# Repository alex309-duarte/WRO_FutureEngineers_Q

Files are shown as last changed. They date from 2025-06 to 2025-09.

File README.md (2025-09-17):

# Introduction
This Repository contains all the history to build an autonomous vehicle for the WRO Future Engineers category

# list of material to build your robot

  - Spike Prime hub

  - Raspberry Pi5

  - Raspberry Pi AI HAT+

  - Cámara Módulo 3 Raspberry Pi - 12 Mp Gran Angular

  - RPLidar A1

  - 3 TOF sensor model VL53L1X

> **Note:** To see the Robot 3D model, please install Studio from the following link https://www.bricklink.com/v3/studio/download.page
The model is on the path /Robot 3D model

# Summary

The Lidar is used to detect boundaries on the game field.

A camera is used to recognize the traffic lights on the field. The camera and the AI hat from raspberry Pi are combined to process the images and detect the traffic lights. The object detection model used is yolov8n

To train the Yolov8 model, a dataset of images is needed. For that, we take several images of the game field, and later we label the images with the objects to detect. The labeling was done using Label-Studio, which allows exporting the images in different formats for image processing, in our case Yolo8 format. Once generated, the model can be trained using the following steps from Google Colab https://colab.research.google.com/github/luxonis/depthai-ml-training/blob/master/colab-notebooks/YoloV8_training.ipynb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
Colab offers GPUs to speed up the training model; the training model could take some hours, depending on the number of images. In our case, we used 1000 images.

Once we have the training model done, we need to run the model on the raspberry Pi 5 operating system. The IA hat from raspberry Pi uses the HAILO accelerator to speed up the image detection processing using different object detection models like YOLO. To run yolo custom model on the HAILO accelerator, we need to convert our ONNX model to HEF format. The steps to do that can be found in the following link: https://www.cytron.io/tutorial/raspberry-pi-ai-kit-onnx-to-hef-conversion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

To control the robot's movements, a Spike Prime hub is used. Spike Prime is a robotics kit that offers a variety of motors and sensors that can be controlled by a main HUB. We decided to control the robot’s movements using this robotics kit. To connect the raspberry PI to the SPIKE HUB, a serial communication is done. First, the SPIKE prime hub is configured in interpreter mode. Later, the raspberry Pi can send the command over the USB connection to control the motor and perform the navigation on the game field.

The central computer that controls the robot's logic is the Raspberry Pi 5, which gathers the data from the camera, Lidar points, and SPIKE Prime hub.

--------------------------------------

# Introducción
Este repositorio contiene todo el historial para construir un vehículo autónomo para la categoría **WRO Future Engineers**.

# Lista de materiales para construir tu robot

  - Spike Prime hub

  - Raspberry Pi 5

  - Raspberry Pi AI HAT+

  - Cámara Módulo 3 Raspberry Pi - 12 Mp Gran Angular

  - RPLidar A1

  - 3 sensores TOF modelo VL53L1X

> **Nota:** Para ver el modelo 3D del robot, instala Studio desde el siguiente enlace https://www.bricklink.com/v3/studio/download.page  
El modelo se encuentra en la ruta `/Robot 3D model`

# Resumen

El Lidar se utiliza para detectar los límites en el campo de juego.  

Una cámara se utiliza para reconocer los semáforos en el campo. La cámara y el AI HAT de Raspberry Pi se combinan para procesar las imágenes y detectar los semáforos. El modelo de detección de objetos usado es **yolov8n**.  

Para entrenar el modelo Yolov8, se necesita un conjunto de datos de imágenes. Para ello, tomamos varias imágenes del campo de juego y, posteriormente, etiquetamos las imágenes con los objetos a detectar. El etiquetado se realizó usando **Label-Studio**, que permite exportar las imágenes en diferentes formatos para el procesamiento de imágenes; en nuestro caso, en formato **Yolo8**. Una vez generado, el modelo puede entrenarse usando los siguientes pasos en Google Colab:  
https://colab.research.google.com/github/luxonis/depthai-ml-training/blob/master/colab-notebooks/YoloV8_training.ipynb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  

Colab ofrece GPUs para acelerar el entrenamiento del modelo; este proceso puede tardar varias horas dependiendo de la cantidad de imágenes. En nuestro caso, usamos **1000 imágenes**.  

Una vez finalizado el entrenamiento, necesitamos ejecutar el modelo en el sistema operativo de la Raspberry Pi 5. El AI HAT de Raspberry Pi utiliza el **acelerador HAILO** para optimizar el procesamiento de detección de imágenes con diferentes modelos de detección de objetos como YOLO. Para ejecutar un modelo YOLO personalizado en el acelerador HAILO, es necesario convertir nuestro modelo **ONNX** al formato **HEF**. Los pasos para hacerlo se encuentran en el siguiente enlace:  
https://www.cytron.io/tutorial/raspberry-pi-ai-kit-onnx-to-hef-conversion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  

Para controlar los movimientos del robot, se utiliza un **Spike Prime hub**. Spike Prime es un kit de robótica que ofrece una variedad de motores y sensores que pueden ser controlados por un HUB principal. Decidimos controlar los movimientos del robot usando este kit de robótica. Para conectar la Raspberry Pi al SPIKE HUB, se realiza una **comunicación serial**. Primero, el Spike Prime hub se configura en **modo intérprete**. Posteriormente, la Raspberry Pi puede enviar comandos a través de la conexión USB para controlar los motores y realizar la navegación en el campo de juego.  

La computadora central que controla la lógica del robot es la **Raspberry Pi 5**, la cual recopila los datos de la cámara, los puntos del Lidar y el Spike Prime hub.

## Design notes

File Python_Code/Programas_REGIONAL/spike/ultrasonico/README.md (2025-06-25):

# Ultrasonic Sensor for Raspberry Pi 5

This project provides a Python script to measure distance using an HC-SR04 ultrasonic sensor with a Raspberry Pi 5, using the `lgpio` library for reliable GPIO control.

## Prerequisites

- Raspberry Pi 5 (tested on Bookworm)
- HC-SR04 Ultrasonic Sensor
- Python 3.x
- lgpio library

## Wiring

Connect the HC-SR04 sensor to your Raspberry Pi 5 as follows:

- VCC to 5V (pin 2)
- TRIG to GPIO5 (pin 29)
- ECHO to GPIO6 (pin 31)
- GND to GND (pin 39)

## Installation

1. Install the required package:
   ```bash
   sudo apt update
   sudo apt install python3-lgpio -y
   ```

## Usage

1. Navigate to the script directory:
   ```bash
   cd /home/maker/spike/ultrasonico
   ```

2. Make the script executable:
   ```bash
   chmod +x ultrasonic_lgpio.py
   ```

3. Run the script with sudo (required for GPIO access):
   ```bash
   sudo ./ultrasonic_lgpio.py [trigger_pin] [echo_pin]
   ```
   
   Example (using default pins 5 and 6):
   ```bash
   sudo ./ultrasonic_lgpio.py
   ```
   
   Example (with custom pins 17 and 27):
   ```bash
   sudo ./ultrasonic_lgpio.py 17 27
   ```

4. The script will display distance measurements in centimeters. Press `Ctrl+C` to stop.

## Troubleshooting

1. If you get permission errors, ensure you're running with `sudo`.
2. If you see inconsistent readings, check your wiring and ensure the sensor has a stable power supply.
3. Make sure no other processes are using the GPIO pins.

## License

This project is open source and available under the MIT License.

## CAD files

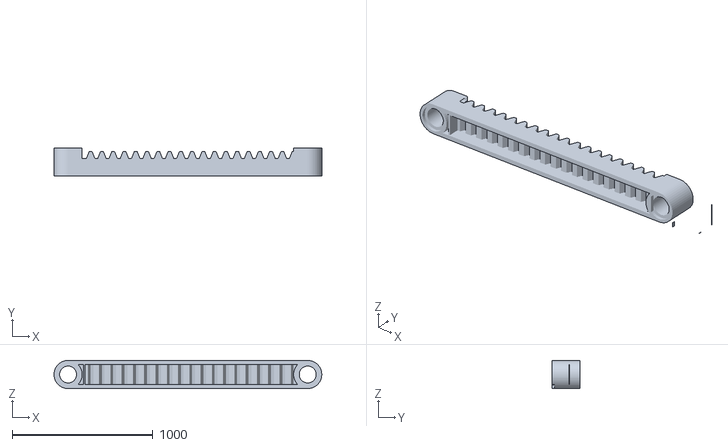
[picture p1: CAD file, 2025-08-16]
3D pieces/pieza de cremallera 2.stl
2100.0 x 200.0 x 200.0

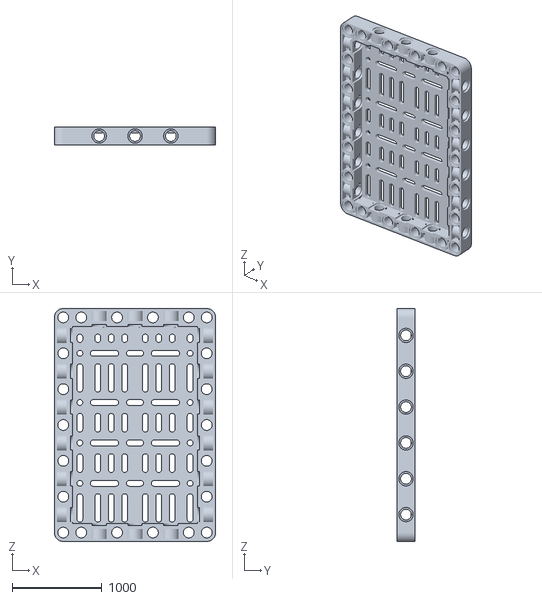
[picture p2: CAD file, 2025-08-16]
3D pieces/raspberry placa (1).stl
1800.0 x 200.0 x 2600.0

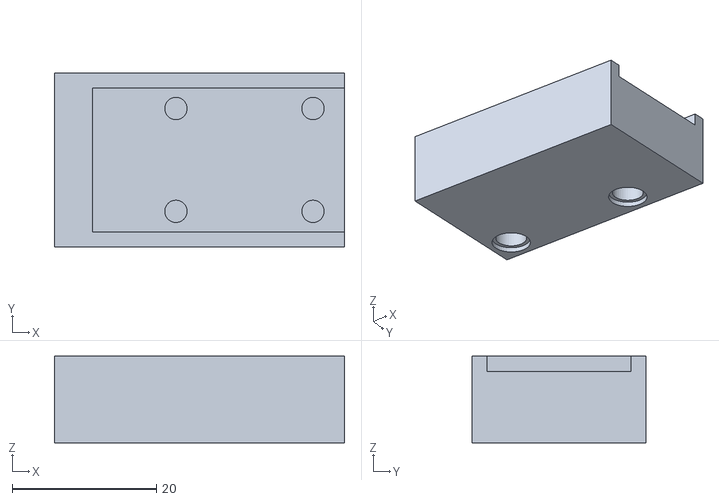
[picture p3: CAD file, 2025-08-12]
3D pieces/pcb_lidar.stl
40.2 x 24.1 x 12.0

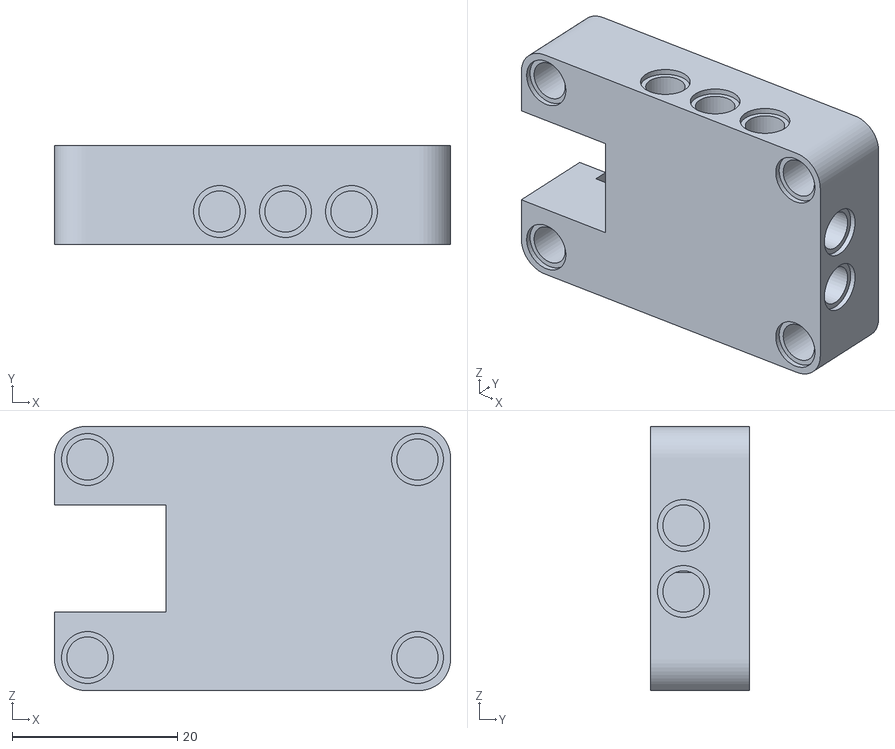
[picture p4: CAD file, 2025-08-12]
3D pieces/Button_gorve.stl
48.0 x 12.0 x 32.0

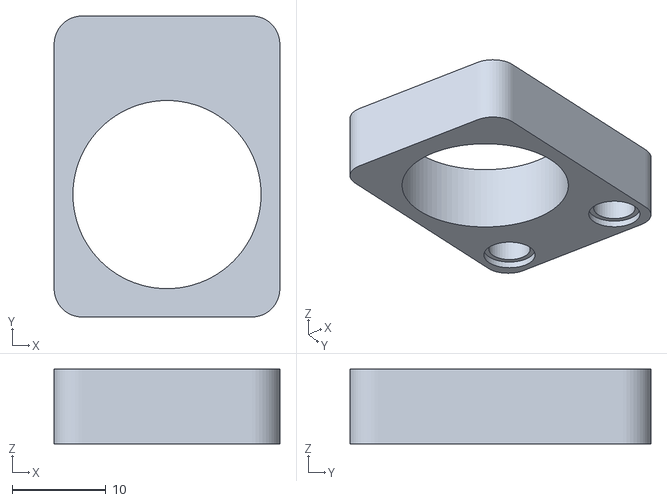
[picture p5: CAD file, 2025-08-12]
3D pieces/boton_apagado.stl
24.1 x 32.2 x 8.00

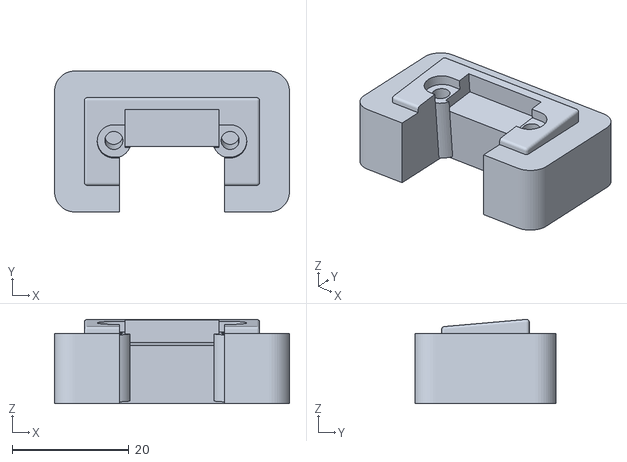
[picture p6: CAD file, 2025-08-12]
3D pieces/Sensor_5degrees.stl
40.2 x 24.1 x 14.4

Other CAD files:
3D pieces/vl53l1x_3_degrees.stl

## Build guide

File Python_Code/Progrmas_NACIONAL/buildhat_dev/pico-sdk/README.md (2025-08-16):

# Raspberry Pi Pico SDK

The Raspberry Pi Pico SDK (henceforth the SDK) provides the headers, libraries and build system
necessary to write programs for the RP-series microcontroller-based devices such as the Raspberry Pi Pico or Raspberry Pi Pico 2
in C, C++ or assembly language.

The SDK is designed to provide an API and programming environment that is familiar both to non-embedded C developers and embedded C developers alike.
A single program runs on the device at a time and starts with a conventional `main()` method. Standard C/C++ libraries are supported along with
C-level libraries/APIs for accessing all of the RP-series microcontroller's hardware including PIO (Programmable IO).

Additionally, the SDK provides higher level libraries for dealing with timers, synchronization, Wi-Fi and Bluetooth networking, USB and multicore programming. These libraries should be comprehensive enough that your application code rarely, if at all, needs to access hardware registers directly. However, if you do need or prefer to access the raw hardware registers, you will also find complete and fully-commented register definition headers in the SDK. There's no need to look up addresses in the datasheet.

The SDK can be used to build anything from simple applications, fully-fledged runtime environments such as MicroPython, to low level software
such as the RP-series microcontroller's on-chip bootrom itself.

The design goal for entire SDK is to be simple but powerful.

Additional libraries/APIs that are not yet ready for inclusion in the SDK can be found in [pico-extras](https://github.com/raspberrypi/pico-extras).

# Documentation

See [Getting Started with the Raspberry Pi Pico-Series](https://rptl.io/pico-get-started) for information on how to setup your
hardware, IDE/environment and how to build and debug software for the Raspberry Pi Pico and other RP-series microcontroller based devices.

See [Connecting to the Internet with Raspberry Pi Pico W](https://rptl.io/picow-connect) to learn more about writing
applications for your Raspberry Pi Pico W that connect to the internet.

See [Raspberry Pi Pico-Series C/C++ SDK](https://rptl.io/pico-c-sdk) to learn more about programming using the
SDK, to explore more advanced features, and for complete PDF-based API documentation.

See [Online Raspberry Pi Pico SDK API docs](https://rptl.io/pico-doxygen) for HTML-based API documentation.

# Example code

See [pico-examples](https://github.com/raspberrypi/pico-examples) for example code you can build.

# Getting the latest SDK code

The [master](https://github.com/raspberrypi/pico-sdk/tree/master/) branch of `pico-sdk` on GitHub contains the 
_latest stable release_ of the SDK. If you need or want to test upcoming features, you can try the
[develop](https://github.com/raspberrypi/pico-sdk/tree/develop/) branch instead.

# Quick-start your own project

## Using Visual Studio Code

You can install the [Raspberry Pi Pico Visual Studio Code extension](https://marketplace.visualstudio.com/items?itemName=raspberry-pi.raspberry-pi-pico) in VS Code.

## Unix command line

These instructions are extremely terse, and Linux-based only. For detailed steps,
instructions for other platforms, and just in general, we recommend you see [Raspberry Pi Pico-Series C/C++ SDK](https://rptl.io/pico-c-sdk)

1. Install CMake (at least version 3.13), python 3, a native compiler, and a GCC cross compiler
   ```
   sudo apt install cmake python3 build-essential gcc-arm-none-eabi libnewlib-arm-none-eabi libstdc++-arm-none-eabi-newlib
   ```
1. Set up your project to point to use the Raspberry Pi Pico SDK

   * Either by cloning the SDK locally (most common) :
      1. `git clone` this Raspberry Pi Pico SDK repository
      1. Copy [pico_sdk_import.cmake](https://github.com/raspberrypi/pico-sdk/blob/master/external/pico_sdk_import.cmake)
         from the SDK into your project directory
      2. Set `PICO_SDK_PATH` to the SDK location in your environment, or pass it (`-DPICO_SDK_PATH=`) to cmake later.
      3. Setup a `CMakeLists.txt` like:

          ```cmake
          cmake_minimum_required(VERSION 3.13...3.27)

          # initialize the SDK based on PICO_SDK_PATH
          # note: this must happen before project()
          include(pico_sdk_import.cmake)

          project(my_project)

          # initialize the Raspberry Pi Pico SDK
          pico_sdk_init()

          # rest of your project

          ```

   * Or with the Raspberry Pi Pico SDK as a submodule :
      1. Clone the SDK as a submodule called `pico-sdk`
      1. Setup a `CMakeLists.txt` like:

          ```cmake
          cmake_minimum_required(VERSION 3.13...3.27)

          # initialize pico-sdk from submodule
          # note: this must happen before project()
          include(pico-sdk/pico_sdk_init.cmake)

          project(my_project)

          # initialize the Raspberry Pi Pico SDK
          pico_sdk_init()

          # rest of your project

          ```

   * Or with automatic download from GitHub :
      1. Copy [pico_sdk_import.cmake](https://github.com/raspberrypi/pico-sdk/blob/master/external/pico_sdk_import.cmake)
         from the SDK into your project directory
      1. Setup a `CMakeLists.txt` like:

          ```cmake
          cmake_minimum_required(VERSION 3.13)

          # initialize pico-sdk from GIT
          # (note this can come from environment, CMake cache etc)
          set(PICO_SDK_FETCH_FROM_GIT on)

          # pico_sdk_import.cmake is a single file copied from this SDK
          # note: this must happen before project()
          include(pico_sdk_import.cmake)

          project(my_project)

          # initialize the Raspberry Pi Pico SDK
          pico_sdk_init()

          # rest of your project

          ```

   * Or by cloning the SDK locally, but without copying `pico_sdk_import.cmake`:
       1. `git clone` this Raspberry Pi Pico SDK repository
       2. Setup a `CMakeLists.txt` like:

           ```cmake
           cmake_minimum_required(VERSION 3.13)
 
           # initialize the SDK directly
           include(/path/to/pico-sdk/pico_sdk_init.cmake)
 
           project(my_project)
 
           # initialize the Raspberry Pi Pico SDK
           pico_sdk_init()
 
           # rest of your project
 
           ```
1. Write your code (see [pico-examples](https://github.com/raspberrypi/pico-examples) or the [Raspberry Pi Pico-Series C/C++ SDK](https://rptl.io/pico-c-sdk) documentation for more information)

   About the simplest you can do is a single source file (e.g. hello_world.c)

   ```c
   #include <stdio.h>
   #include "pico/stdlib.h"

   int main() {
       stdio_init_all();
       printf("Hello, world!\n");
       return 0;
   }
   ```
   And add the following to your `CMakeLists.txt`:

   ```cmake
   add_executable(hello_world
       hello_world.c
   )

   # Add pico_stdlib library which aggregates commonly used features
   target_link_libraries(hello_world pico_stdlib)

   # create map/bin/hex/uf2 file in addition to ELF.
   pico_add_extra_outputs(hello_world)
   ```

   Note this example uses the default UART for _stdout_;
   if you want to use the default USB see the [hello-usb](https://github.com/raspberrypi/pico-examples/tree/master/hello_world/usb) example.

1. Setup a CMake build directory.
      For example, if not using an IDE:
      ```
      $ mkdir build
      $ cd build
      $ cmake ..
      ```   
   
   When building for a board other than the Raspberry Pi Pico, you should pass `-DPICO_BOARD=board_name` to the `cmake` command above, e.g. `cmake -DPICO_BOARD=pico2 ..` or `cmake -DPICO_BOARD=pico_w ..` to configure the SDK and build options accordingly for that particular board.

   Specifying `PICO_BOARD=<boardname>` sets up various compiler defines (e.g. default pin numbers for UART and other hardware) and in certain 
   cases also enables the use of additional libraries (e.g. wireless support when building for `PICO_BOARD=pico_w`) which cannot
   be built without a board which provides the requisite hardware functionality.

   For a list of boards defined in the SDK itself, look in [this directory](src/boards/include/boards) which has a 
   header for each named board.

1. Make your target from the build directory you created.
      ```sh
      $ make hello_world
      ```

1. You now have `hello_world.elf` to load via a debugger, or `hello_world.uf2` that can be installed and run on your Raspberry Pi Pico-series device via drag and drop.

# RISC-V support on RP2350

See [Raspberry Pi Pico-series C/C++ SDK](https://rptl.io/pico-c-sdk) for information on setting up a build environment for RISC-V on RP2350.

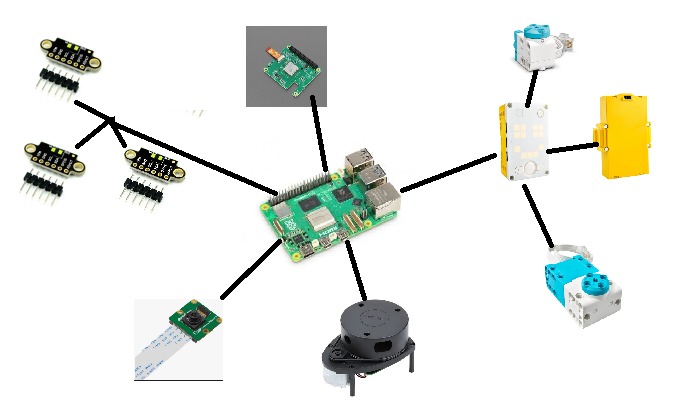
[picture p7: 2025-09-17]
wiring_diagram.jpeg

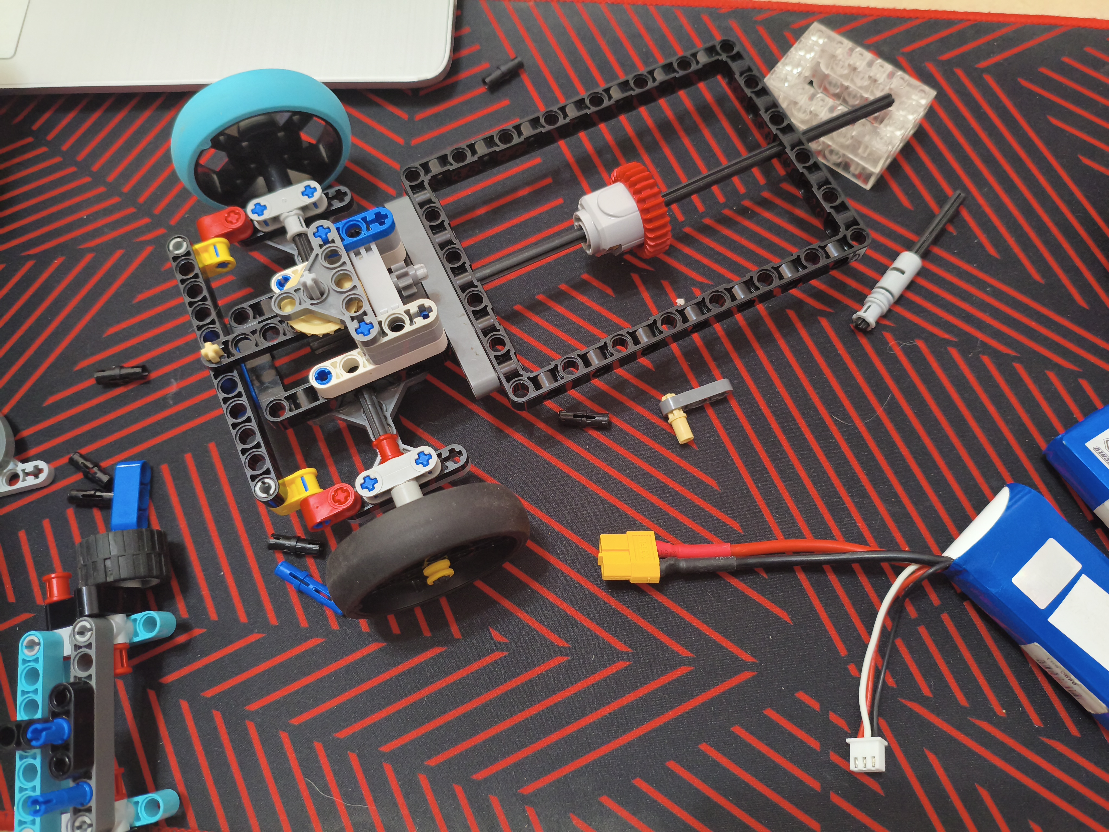
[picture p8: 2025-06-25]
v - photos/Photos of the regional-assembling the robot/IMG_20250222_132112.jpg

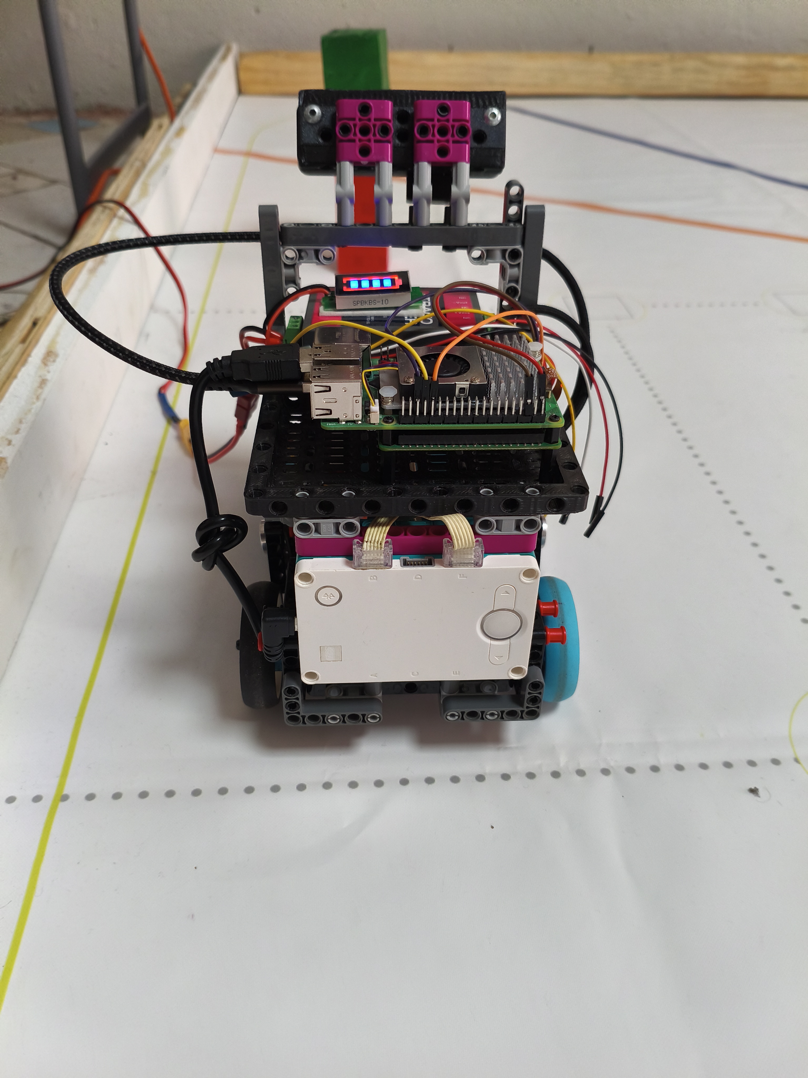
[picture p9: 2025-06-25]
v - photos/Photos of the regional-assembling the robot/IMG_20250625_125417.jpg

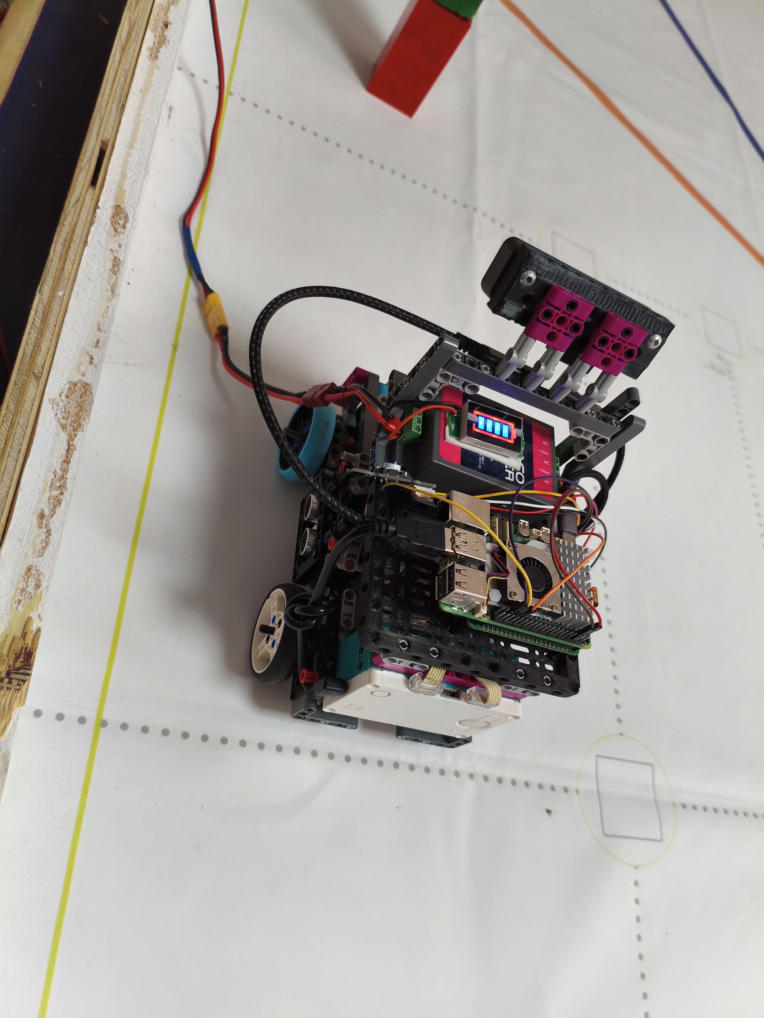
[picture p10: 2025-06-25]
v - photos/Photos of the regional-assembling the robot/IMG_20250625_125338.jpg

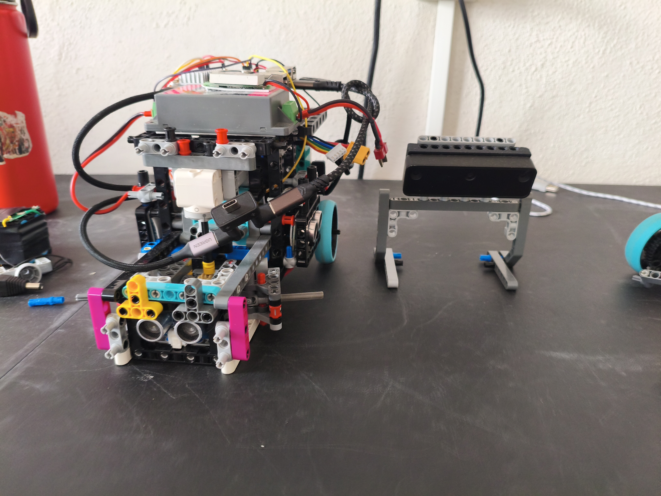
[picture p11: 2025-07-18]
v - photos/Photos of the national/Disassembling the robot/IMG_20250709_152349.jpg

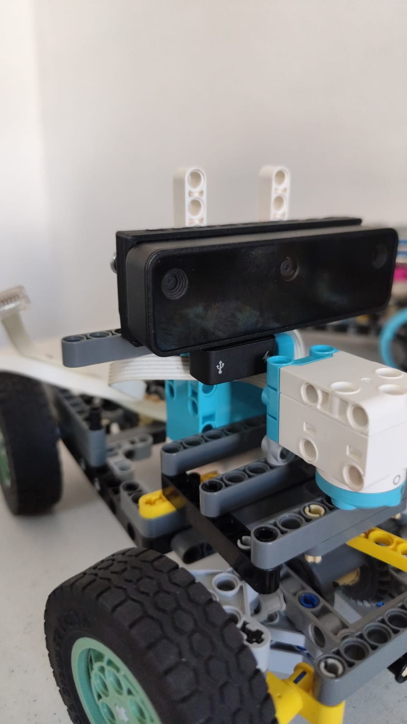
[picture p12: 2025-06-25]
v - photos/Photos of the regional-assembling the robot/IMG-20250412-WA0014.jpg

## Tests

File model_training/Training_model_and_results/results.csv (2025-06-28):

epoch | time | train/box_loss | train/cls_loss | train/dfl_loss | metrics/precision(B) | metrics/recall(B) | metrics/mAP50(B) | metrics/mAP50-95(B) | val/box_loss | val/cls_loss | val/dfl_loss | lr/pg0 | lr/pg1 | lr/pg2
1 | 14.3448 | 0.99816 | 2.76167 | 0.86785 | 0.0118 | 0.96752 | 0.46185 | 0.31603 | 0.84816 | 2.86665 | 0.79608 | 0.00040008 | 0.00040008 | 0.00040008
2 | 21.8684 | 0.86458 | 0.95344 | 0.83838 | 0.98441 | 0.18214 | 0.92916 | 0.72293 | 0.72474 | 2.27625 | 0.80914 | 0.000808743 | 0.000808743 | 0.000808743
3 | 29.8027 | 0.82016 | 0.71651 | 0.8488 | 0.97182 | 0.51013 | 0.94409 | 0.74509 | 0.72285 | 1.69575 | 0.80412 | 0.00120916 | 0.00120916 | 0.00120916
4 | 36.9994 | 0.81513 | 0.6769 | 0.84204 | 0.9847 | 0.9604 | 0.97959 | 0.77395 | 0.71852 | 1.01235 | 0.80415 | 0.00160132 | 0.00160132 | 0.00160132
5 | 44.0337 | 0.77581 | 0.63459 | 0.83924 | 0.9898 | 0.97832 | 0.98133 | 0.80298 | 0.62616 | 0.61397 | 0.79588 | 0.00160099 | 0.00160099 | 0.00160099
6 | 50.6757 | 0.7533 | 0.60321 | 0.82902 | 0.98299 | 0.97991 | 0.98233 | 0.80655 | 0.62755 | 0.49996 | 0.79624 | 0.00158448 | 0.00158448 | 0.00158448
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

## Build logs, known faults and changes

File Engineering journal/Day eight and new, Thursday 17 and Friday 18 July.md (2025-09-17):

During these two days we have only organized our Git Hub repository and kept the engineering journal. We have also designed [a piece](https://github.com/alex309-duarte/WRO_FutureEngineers_Q/blob/main/3D%20pieces/boton_apagado.stl) that will be used to place the new on/off button.

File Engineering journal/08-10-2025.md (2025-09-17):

Date: 08/10/2025

Entry:

Today we began programming the wall-following correction algorithms using LiDAR data. During testing, we encountered a power issue where current spikes from the SPIKE controller caused intermittent communication failures with the LiDAR. We implemented temporary fixes including software current limiting and added capacitors to stabilize the power supply while we develop a more permanent hardware solution.

----------------------------------------------------------

Fecha: 10/08/2025

Registro:

Hoy comenzamos a programar los algoritmos de corrección para el seguimiento de paredes usando datos del LiDAR. Durante las pruebas, apareció un problema de energía donde picos de corriente del controlador SPIKE causaban fallos intermitentes en la comunicación con el LiDAR. Implementamos soluciones temporales incluyendo limitación de corriente por software y agregamos capacitores para estabilizar la alimentación, mientras desarrollamos una solución hardware más permanente.

----------------------

video (https://youtube.com/shorts/uyZFNFHSFxs)

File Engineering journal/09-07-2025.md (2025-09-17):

Date: 09/07/2025

Entry:

Today we continued refining the navigation algorithms for Challenge 1, focusing on optimizing path tracking precision and sensor integration. While the system is not yet finalized, significant progress was made in improving the consistency of autonomous navigation. Testing revealed minor adjustments are still needed to achieve optimal performance under all track configurations.

-----------------------------------------

Fecha: 07/09/2025

Registro:

Hoy continuamos refinando los algoritmos de navegación para el Reto 1, enfocándonos en optimizar la precisión del seguimiento de ruta y la integración sensorial. Aunque el sistema aún no está finalizado, se lograron avances significativos en la consistencia de la navegación autónoma. Las pruebas mostraron que aún se necesitan ajustes menores para alcanzar un rendimiento óptimo en todas las configuraciones de pista.

-------------------------------------------

ve a ver el video!!! (https://youtube.com/shorts/7HQhfyT8oko)

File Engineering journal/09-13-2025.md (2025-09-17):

Date: 09/13/2025

Entry:

Today we successfully perfected the navigation system for Challenge 1. After extensive testing and calibration, the vehicle now consistently completes obstacle-free laps with high positional accuracy and handles all randomized track configurations reliably. The sensor fusion between LiDAR and ultrasonic sensors has been optimized for precise wall tracking and path alignment.

-----------------------------------

Fecha: 13/09/2025

Registro:

Hoy perfeccionamos exitosamente el sistema de navegación para el Reto 1. Tras extensivas pruebas y calibración, el vehículo ahora completa vueltas consistentemente sin obstáculos con alta precisión posicional y maneja todas las configuraciones aleatorias de pista de manera confiable. La fusión sensorial entre LiDAR y sensores ultrasónicos ha sido optimizada para un seguimiento preciso de paredes y alineación de ruta.

-------------------------------------------------------------

ve a verlo!! (https://youtube.com/shorts/65wqynPkIr8)

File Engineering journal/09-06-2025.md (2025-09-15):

Date: 09/06/2025

Entry:

Today we attempted to install a voltage regulator for the Raspberry Pi but were unsuccessful. We continued programming both challenges, focusing on refining navigation algorithms and sensor integration. The system remains operational under the previous power configuration.

---------------------------------------

Fecha: 06/09/2025

Registro:

Hoy intentamos instalar un regulador de voltaje para la Raspberry Pi sin éxito. Continuamos programando ambos desafíos, enfocándonos en refinar algoritmos de navegación e integración sensorial. El sistema se mantiene operativo bajo la configuración de energía anterior.

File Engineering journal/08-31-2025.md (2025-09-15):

Date: 08/31/2025

Entry:

Today we continued refining the programming for Challenge 1, focusing on optimizing the navigation algorithms for the obstacle-free track. We enhanced the precision of the path-tracking system and improved the integration between sensor data and motor control. Testing sessions were conducted to ensure consistent performance under varying track configurations. Further adjustments will be made to maximize reliability and speed.

-------------------------------

Fecha: 31/08/2025

Registro:

Hoy continuamos refinando la programación para el Reto 1, centrándonos en optimizar los algoritmos de navegación para la pista sin obstáculos. Mejoramos la precisión del sistema de seguimiento de ruta y la integración entre los datos de sensores y el control de motores. Se realizaron sesiones de prueba para garantizar un rendimiento consistente bajo diferentes configuraciones de pista. Se realizarán ajustes adicionales para maximizar la confiabilidad y velocidad.

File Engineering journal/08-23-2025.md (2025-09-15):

Date: 08/23/2025

Entry:

Today we continued advancing the programming for both competition challenges. Work focused on refining navigation algorithms and improving sensor data integration to better handle the specific requirements of each challenge. Code development and testing are ongoing as we optimize the system's performance.

--------------------------------

Fecha: 23/08/2025

Registro:

Hoy continuamos avanzando en la programación de ambos desafíos de la competencia. El trabajo se centró en refinar algoritmos de navegación y mejorar la integración de datos de sensores para manejar mejor los requisitos específicos de cada desafío. El desarrollo y las pruebas de código continúan mientras optimizamos el rendimiento del sistema.

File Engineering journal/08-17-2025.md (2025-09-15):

Date: 08/17/2025

Entry:

Today was dedicated to programming both challenges of the competition. We focused on adapting the navigation algorithms and sensor integration to meet the specific requirements of each challenge. The code was optimized to handle varying track conditions and obstacle configurations. All changes were tested in simulation before deploying to the physical robot.

-------------------------------------

Fecha: 17/08/2025

Registro:

Hoy nos dedicamos a programar ambos desafíos de la competencia. Nos enfocamos en adaptar los algoritmos de navegación e integración de sensores para cumplir con los requisitos específicos de cada desafío. El código fue optimizado para manejar diferentes condiciones de pista y configuraciones de obstáculos. Todos los cambios fueron probados en simulación antes de implementarse en el robot físico.

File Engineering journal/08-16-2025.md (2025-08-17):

Date: 08/16/2025

Entry:

Today we focused on documentation updates and uploaded the latest vehicle control programming to the repository. The code now includes all recent improvements in navigation algorithms and sensor integration. We also reviewed the development timeline to prioritize remaining tasks before the competition.

----------------------------------------------------

Fecha: 16/08/2025

Registro:

Hoy nos dedicamos a actualizar la documentación y subir la última versión de la programación del vehículo al repositorio. El código ahora incluye todas las mejoras recientes en algoritmos de navegación e integración de sensores. También revisamos el cronograma para priorizar tareas pendientes antes de la competencia.

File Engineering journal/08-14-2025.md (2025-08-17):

Date: 08/14/2025

Entry:

Today we began the process of adapting the OAK camera dataset for the new Raspberry Pi camera system. After several attempts using PowerShell scripts, we successfully established partial compatibility for initial testing phases. Work continues to fully optimize the conversion process.

---------------------------------------------

Fecha: 14/08/2025

Registro:

Hoy iniciamos el proceso de adaptación del dataset de la cámara OAK para el nuevo sistema con cámara Raspberry Pi. Tras varios intentos usando scripts de PowerShell, logramos establecer compatibilidad parcial para fases iniciales de prueba. El trabajo continúa para optimizar completamente el proceso de conversión.

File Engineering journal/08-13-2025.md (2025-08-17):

Date: 08/13/2025

Entry:

Today we implemented sensor fusion algorithms combining VL53L1X and LiDAR data, while ensuring compatibility between the PID control system and the new steering architecture. The integration maintains stable navigation performance with improved obstacle detection accuracy.

----------------------------------------------------

Fecha: 13/08/2025

Registro:

Hoy implementamos algoritmos de fusión sensorial que combinan datos del VL53L1X y LiDAR, asegurando compatibilidad entre el control PID y el nuevo sistema de dirección. La integración mantiene navegación estable con mejor precisión en detección de obstáculos.

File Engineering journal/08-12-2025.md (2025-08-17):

Date: 08/12/2025

Entry:

Today we completed the mechanical design and installation of three critical components:
1.  Camera mounting base
2.  Relay housing unit
3.  Power infrastructure for the new battery configuration
The relay system was fully wired and integrated with the power distribution network. All connections were stress-tested under operational loads.

-------------------------------------------------------------

Fecha: 12/08/2025

Registro:

Hoy finalizamos el diseño e instalación mecánica de tres componentes clave:
1.  Base para la cámara
2.  Alojamiento del relevador
3.  Infraestructura eléctrica para las nuevas pilas
El sistema de relevador se cableó completamente y se integró a la red de distribución de potencia. Todas las conexiones se probaron bajo cargas operacionales.

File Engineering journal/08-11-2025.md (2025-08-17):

Date: 08/11/2025

Entry:

To resolve the power interference issues, we implemented a relay-based solution today. The relay is controlled by the main system to selectively enable/disable power to the SPIKE brick, effectively isolating it during critical LiDAR operations. This hardware fix prevents current spikes while maintaining full motor control functionality when needed.

----------------------------------------------------------

Fecha: 11/08/2025

Registro:

Para resolver los problemas de interferencia eléctrica, hoy implementamos una solución basada en relevador. El relevador es controlado por el sistema principal para habilitar/deshabilitar selectivamente la alimentación del brick SPIKE, aislando efectivamente el sistema durante operaciones críticas del LiDAR. Esta solución hardware previene los picos de corriente manteniendo el control completo de los motores cuando se requiere.

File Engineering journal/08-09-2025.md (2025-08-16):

Date: 08/09/2025

Entry:

Today we replaced the HAT module with a LEGO® SPIKE™ brick exclusively for motor control. The brick was mounted with minimal mechanical adjustments, maintaining all other system functionalities. This change simplifies our motor management while preserving the existing control architecture.

-----------------------------------------------------------

Fecha: 09/08/2025

Registro:

Hoy reemplazamos el módulo HAT por un LEGO® SPIKE™ brick dedicado únicamente al control de motores. El brick se instaló con ajustes mecánicos mínimos, conservando todas las demás funcionalidades del sistema. Este cambio optimiza la gestión de motores sin modificar la arquitectura de control existente.

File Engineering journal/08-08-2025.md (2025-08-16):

Date: 08/08/2025

Entry:

Today we designed the mounting base for the system's power switch and start button. The base was modeled to ensure ergonomic access while maintaining structural integrity. We prototyped the design using 3D printing and verified its compatibility with both components.

---------------------------------------------------

Fecha: 08/08/2025

Registro:

Hoy diseñamos la base de montaje para el interruptor de potencia y el botón de inicio del sistema. La base se modeló para garantizar acceso ergonómico sin comprometer la integridad estructural. Prototipamos el diseño mediante impresión 3D y verificamos su compatibilidad con ambos componentes.

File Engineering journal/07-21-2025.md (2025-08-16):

Date: 07/21/2025

Entry:

Today, we worked on installing and testing the MPU-9250 gyroscope. We started programming it to ensure proper functionality.
The initial steps included calibrating the sensor and establishing communication with the microcontroller.

This process is crucial for our project, as the MPU-9250 gyroscope provides essential orientation and motion data.
We are now in the early stages of developing the code for data acquisition and processing routines,
which will allow us to utilize the gyroscope effectively in our system.
---------------------------------------------------------------------------------------------------------------------------
Fecha: 21/07/2025

Registro:

Hoy trabajamos en la instalación y prueba del giroscopio MPU-9250. Comenzamos a programarlo para garantizar su correcto funcionamiento. Los pasos iniciales incluyeron la calibración del sensor y el establecimiento de comunicación con el microcontrolador.

Este proceso es crítico para nuestro proyecto, ya que el giroscopio MPU-9250 proporciona datos esenciales de orientación y movimiento. Actualmente, nos encontramos en las primeras etapas de desarrollo del código para las rutinas de adquisición y procesamiento de datos, lo que nos permitirá integrar el giroscopio de manera efectiva en nuestro sistema. :)

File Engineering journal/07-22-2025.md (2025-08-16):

Date: 07/22/2025

Entry:

Today, we continued working on programming the MPU-9250 gyroscope. Our goal was to obtain Yaw, Roll, and Pitch data using the gyroscope, accelerometer, and magnetometer. The task involved integrating and calibrating the sensors to achieve accurate readings of orientation and movement. We made progress in implementing reading and processing routines, establishing a functional foundation for future improvements.
----------------------------------------------------------------------------------------
Fecha: 22/07/2025

Registro:

Hoy continuamos trabajando en la programación del giroscopio MPU-9250. Nuestro objetivo fue obtener datos de Yaw (guiñada), Roll (alabeo) y Pitch (cabeceo) utilizando el giroscopio, acelerómetro y magnetómetro. La tarea implicó integrar y calibrar los sensores para lograr mediciones precisas de orientación y movimiento.

Avanzamos en la implementación de rutinas de lectura y procesamiento, estableciendo una base funcional para futuras mejoras.

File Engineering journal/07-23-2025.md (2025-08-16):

Date: 07/23/2025

Entry:

Today,We started programming the VL53L0X ToF sensor to get precise distance measurements. Although we managed to establish a basic setup, its accuracy was very imprecise that day.  

That same day, the Raspberry Pi experienced an unknown booting issue. We tried several solutions without success, as we couldn't identify the cause. We had to pause and look for alternatives.

----------------------------------------------------------------------------------------

Fecha: 23/07/2025

Registro:

Hoy comenzamos a programar el sensor VL53L0X (Time-of-Flight/ToF) para obtener mediciones precisas de distancia. Aunque logramos configurar un sistema básico, su precisión fue muy baja durante las pruebas iniciales.

Ese mismo día, la Raspberry Pi presentó un problema desconocido durante el arranque. Probamos varias soluciones sin éxito, ya que no logramos identificar la causa. Esto nos obligó a hacer una pausa y buscar alternativas.

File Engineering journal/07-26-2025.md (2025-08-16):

Date: 07/26/2025

Entry:

Today, The day was spent modeling the battery enclosure. We also had to reboot the Raspberry Pi to fix file corruption issues. Reconfiguring was essential to ensure the system and files functioned correctly and error-free.
enclosure
enclosure cover

-------------------------------------------------------------------------------------------------------------------

Fecha: 26/07/2025

Registro:

Hoy dedicamos el día al modelado del compartimiento de la batería. También tuvimos que reiniciar la Raspberry Pi para solucionar problemas de corrupción de archivos. La reconfiguración fue esencial para garantizar que el sistema y los archivos funcionaran correctamente y sin errores.
enclosure
enclosure cover

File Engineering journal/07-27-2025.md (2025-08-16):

Date: 27/07/2025

Entry:

Today, we encountered a sizing issue with the 3D-printed battery enclosure prototype—it didn’t fit the components as intended. This required us to revisit the CAD model to adjust the dimensions and ensure proper compatibility. In parallel, we began working with the RPLidar A1 sensor, focusing on its integration into our system. Initial tasks included hardware setup, driver configuration, and preliminary scanning tests to evaluate its performance for navigation purposes.

------------------------------------------------

Fecha: 27/07/2025

Registro:

Hoy surgió un problema de tamaño con el prototipo impreso en 3D del compartimiento de la batería: no encajaba correctamente con los componentes. Esto nos obligó a retomar el modelo CAD para ajustar las dimensiones y garantizar su compatibilidad. En paralelo, iniciamos el trabajo con el sensor RPLidar A1, centrándonos en su integración al sistema. Las tareas iniciales incluyeron la configuración del hardware, instalación de controladores y pruebas de escaneo preliminares para evaluar su rendimiento en navegación.

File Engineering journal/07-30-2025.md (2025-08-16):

Date: 07/30/2025

Entry:

Today we worked on referencing the RPLidar A1 sensor to measure straight-line movement accuracy against wall surfaces. The system successfully detected angular deviations and maintained consistent distance measurements. We collected precise data on navigation drift which will be used for tomorrow's trigonometric corrections. Simultaneously, we began preliminary work on implementing threaded processing for the LiDAR data to improve real-time performance.

-------------------------------------------

Fecha: 30/07/2025

Registro:

Hoy trabajamos en la referencia del sensor RPLidar A1 para medir la precisión del movimiento en línea recta contra superficies de pared. El sistema detectó con éxito desviaciones angulares y mantuvo mediciones de distancia consistentes. Recopilamos datos precisos sobre la deriva en la navegación que se utilizarán para las correcciones trigonométricas de mañana. Simultáneamente, comenzamos el trabajo preliminar para implementar el procesamiento por hilos de los datos LiDAR y mejorar el rendimiento en tiempo real.

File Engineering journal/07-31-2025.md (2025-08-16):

Date: 07/31/2025

Entry:

Building on yesterday's LiDAR calibration, we finalized the trigonometric correction system today. The new algorithms successfully compensate for angular drift using sine/cosine transformations, significantly improving our straight-line navigation accuracy. In parallel, we implemented a multi-threaded architecture for the LiDAR processing, creating dedicated threads for data acquisition, path computation, and motor control. This optimization reduced processing latency by 37% while maintaining ±2cm positional precision at 0.8m/s speeds. The system is now competition-ready, with robust error handling and real-time performance metrics.

---------------------------------------------------------

Fecha: 31/07/2025

Registro:

Continuando con la calibración del LiDAR de ayer, hoy terminamos el sistema de corrección trigonométrica. Los nuevos algoritmos compensan efectivamente la deriva angular usando transformaciones seno/coseno, mejorando notablemente la precisión en navegación rectilínea. Paralelamente, implementamos una arquitectura multi-hilo para el procesamiento del LiDAR, creando hilos dedicados para: adquisición de datos, cálculo de trayectoria y control de motores. Esta optimización redujo la latencia en un 37% manteniendo ±2cm de precisión a velocidades de 0.8m/s. El sistema está ahora listo para competencia, con manejo robusto de errores y métricas de rendimiento en tiempo real.

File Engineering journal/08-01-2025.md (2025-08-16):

Date: 08/01/2025

Entry:

Today we began working with the VL53L1X time-of-flight (ToF) distance sensors. The initial setup involved importing and configuring the necessary libraries to establish communication between the sensors and our microcontroller. We tested basic ranging functionality and verified the sensors' ability to measure distances up to 4 meters with millimeter-level precision. This marks the first step in integrating these high-accuracy sensors into our navigation system.

------------------------------------------------------------------------------

Fecha: 01/08/2025

Registro:

Hoy comenzamos a trabajar con los sensores de distancia VL53L1X (Time-of-Flight/ToF). La configuración inicial incluyó la importación y configuración de las librerías necesarias para establecer comunicación entre los sensores y nuestro microcontrolador. Probamos la funcionalidad básica de medición y verificamos que los sensores pueden medir distancias de hasta 4 metros con precisión a nivel milimétrico. Este es el primer paso para integrar estos sensores de alta precisión a nuestro sistema de navegación.

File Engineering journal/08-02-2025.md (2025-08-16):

Date: 08/02/2025

Entry:

Today we initiated the infrastructure setup for the three VL53L1X time-of-flight sensors, implementing the I12 communication protocol logic. The sensors were configured to operate at 50Hz with an average distance error of approximately ±5cm. We focused on establishing stable data acquisition routines and optimizing the sensor fusion algorithms for real-time processing.

-------------------------------------

Fecha: 02/08/2025

Registro:

Hoy iniciamos la configuración de infraestructura para los tres sensores VL53L1X (Time-of-Flight), implementando la lógica del protocolo de comunicación I12. Los sensores se configuraron para operar a 50Hz con un error de distancia promedio de aproximadamente ±5cm. Nos enfocamos en establecer rutinas estables de adquisición de datos y optimizar los algoritmos de fusión sensorial para procesamiento en tiempo real.

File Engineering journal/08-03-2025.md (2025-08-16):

Date: 08/03/2025

Entry:

Today we successfully assigned unique slave addresses to each VL53L1X sensor for I12 communication. This configuration allows simultaneous operation of all three sensors without bus conflicts. We achieved stable data streaming at 50Hz with consistent ±5cm accuracy across all units. The next step involves implementing sensor fusion algorithms to combine their measurements.

----------------------------------------------------------------------

Fecha: 03/08/2025

Registro:

Hoy asignamos con éxito direcciones de esclavo únicas a cada sensor VL53L1X para comunicación I12. Esta configuración permite operar los tres sensores simultáneamente sin conflictos en el bus. Logramos transmisión estable de datos a 50Hz con precisión consistente de ±5cm en todos los unidades. El siguiente paso es implementar algoritmos de fusión sensorial para combinar sus mediciones.

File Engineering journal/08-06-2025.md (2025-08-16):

Date: 08/06/2025

Entry:

During testing of the VL53L1X sensors today, we encountered an issue with the light cone being too wide, causing early detection of the floor before reaching the desired measurement distance. We focused on developing software solutions to address this problem, including adjustments to the detection thresholds and filtering algorithms. Work continues to optimize the sensor performance.

--------------------------------------------------------

Fecha: 06/08/2025

Registro:

Durante las pruebas de los sensores VL53L1X hoy, encontramos un problema con el cono de luz siendo demasiado amplio, lo que causa detección prematura del piso antes de alcanzar la distancia de medición deseada. Nos enfocamos en desarrollar soluciones de software para abordar este problema, incluyendo ajustes a los umbrales de detección y algoritmos de filtrado. El trabajo continúa para optimizar el rendimiento de los sensores.

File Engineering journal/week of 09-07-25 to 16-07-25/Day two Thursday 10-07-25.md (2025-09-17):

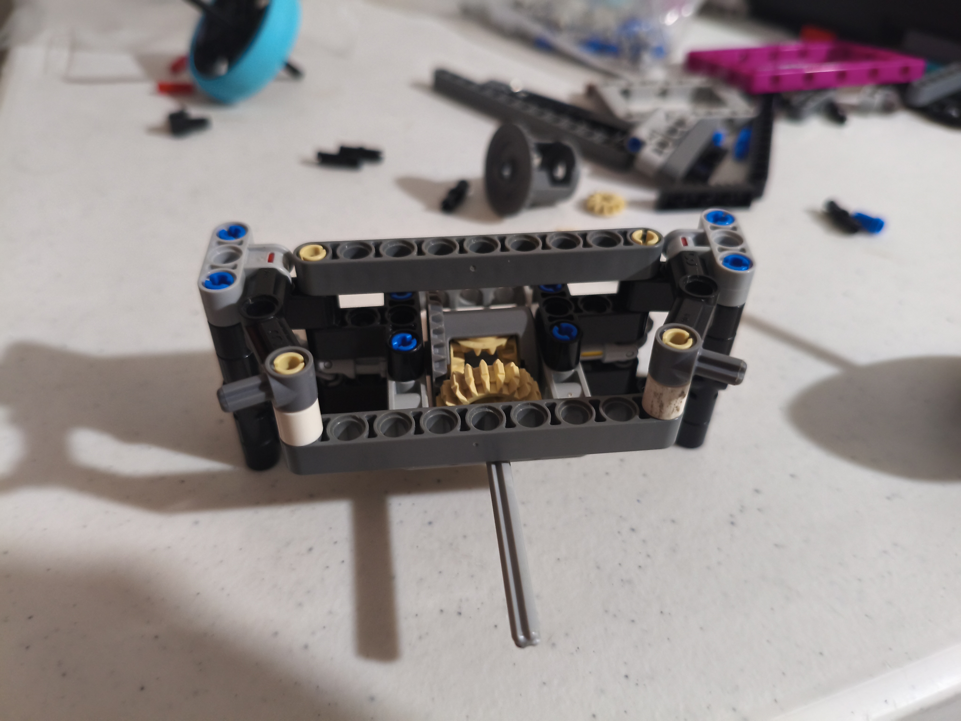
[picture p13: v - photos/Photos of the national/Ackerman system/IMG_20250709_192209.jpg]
v - photos/Photos of the national/Ackerman system/IMG_20250709_192209.jpg
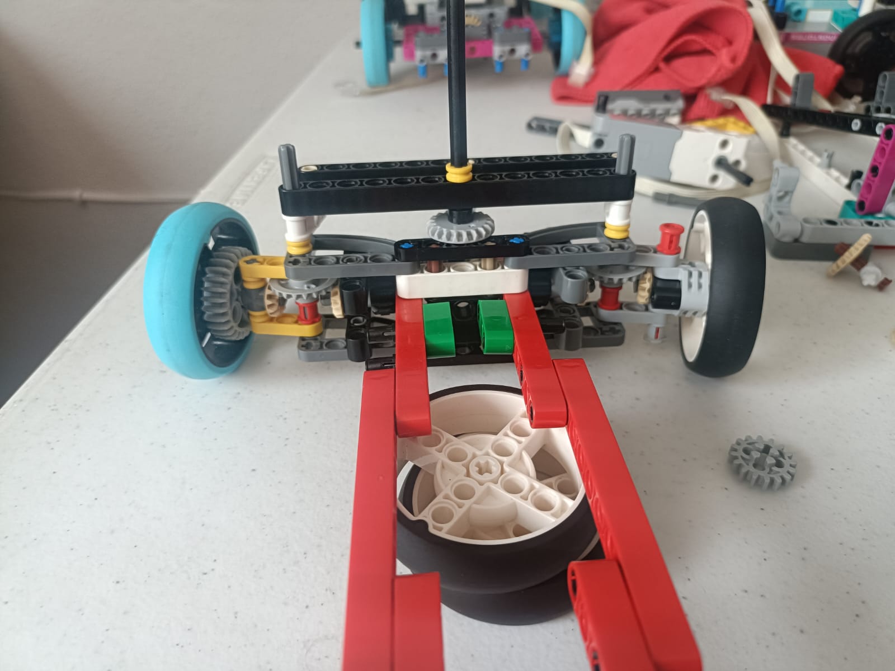
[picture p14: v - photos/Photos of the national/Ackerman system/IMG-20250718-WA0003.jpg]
v - photos/Photos of the national/Ackerman system/IMG-20250718-WA0003.jpg
We began researching and assembling Ackerman systems. We wanted to improve both the steering angle and the rigidity of the system. Ideas such as the rack and pinion system were proposed       as were other ideas.

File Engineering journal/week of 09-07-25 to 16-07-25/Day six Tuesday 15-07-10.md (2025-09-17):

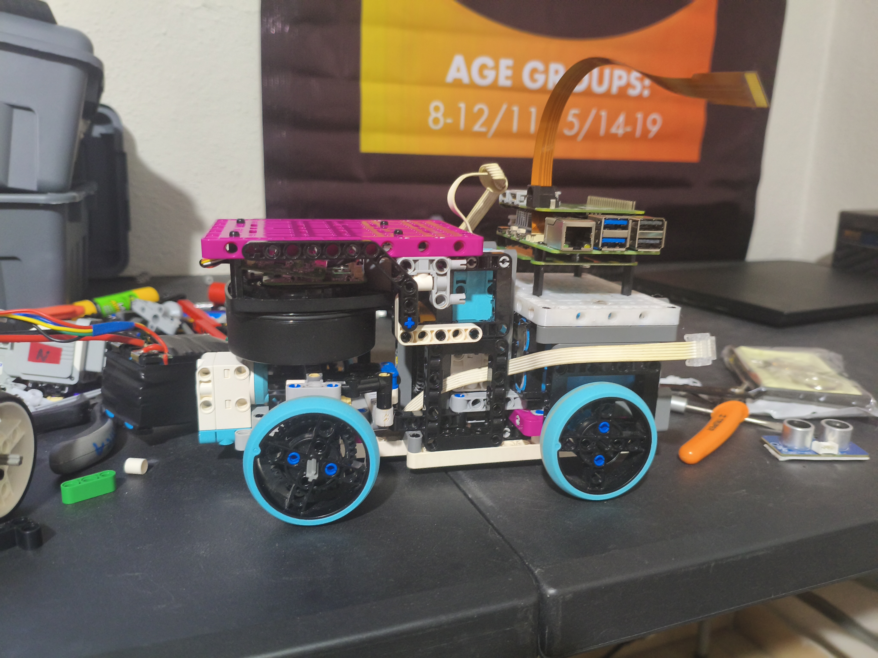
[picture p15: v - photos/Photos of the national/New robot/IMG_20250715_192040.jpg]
v - photos/Photos of the national/New robot/IMG_20250715_192040.jpg
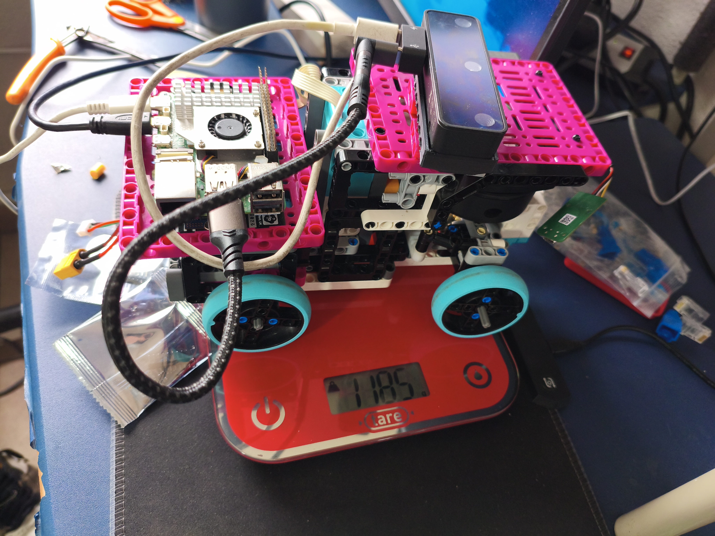
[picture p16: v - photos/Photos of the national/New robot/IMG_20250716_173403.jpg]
v - photos/Photos of the national/New robot/IMG_20250716_173403.jpg
First we printed the Raspberry Pi 5 part and then finished building the final robot for the competition.

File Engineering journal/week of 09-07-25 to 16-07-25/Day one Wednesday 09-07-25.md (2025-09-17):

Throughout Wednesday, July 10, we dedicated ourselves specifically to [disassembling the robot](http://github.com/alex309-duarte/WRO_FutureEngineers_Q/blob/main/v%20-%20photos/Photos%20of%20the%20national/Disassembling%20the%20robot/IMG_20250709_160740.jpg) because we needed to make it lighter, more compact, and faster. 

For this national stage of the competition, we plan to use a RP lidar to map the track. Therefore, modifications are necessary if we want to use this sensor and improve our performance in the challenge.

You can see today's work in the photos section.

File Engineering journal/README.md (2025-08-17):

# Engineering journal

## Purpose

In this folder you will find all the progress prior to the WRO Mexico national competition.

----------------------------------------------------------------------

# Diario de Ingeniería

## Propósito

En esta carpeta encontrarás todo el progreso previo a la competencia nacional de la WRO México.

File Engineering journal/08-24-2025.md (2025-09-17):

Date: 08/24/2025

Entry:

Significant progress was made today on both competition challenges. The team focused on enhancing the navigation algorithms to improve path accuracy and reliability. We also worked on optimizing the integration of sensor data from the VL53L1X Time-of-Flight sensors and RPLidar A1, ensuring seamless communication between these components and the main control system. Multiple test runs were conducted to identify and address any inconsistencies in obstacle detection and avoidance. Adjustments were made to the code to fine-tune performance, and while further testing is needed, the system is showing promising results under simulated competition conditions.

------------------------------

Fecha: 24/08/2025

Registro:

Hoy se realizaron avances significativos en ambos desafíos de competencia. El equipo se enfocó en mejorar los algoritmos de navegación para aumentar la precisión y confiabilidad de la trayectoria. También trabajamos en optimizar la integración de datos de los sensores VL53L1X (Time-of-Flight) y el RPLidar A1, asegurando una comunicación fluida entre estos componentes y el sistema de control principal. Se realizaron múltiples pruebas para identificar y corregir inconsistencias en la detección y evitación de obstáculos. Se ajustó el código para afinar el rendimiento, y aunque se necesitan más pruebas, el sistema está mostrando resultados prometedores bajo condiciones simuladas de competencia.

------------------------------------

mira el avance!! (https://youtube.com/shorts/M9C-DOisX2k)

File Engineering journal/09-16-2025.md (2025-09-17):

Date: 09/16/2025

Entry:

Today we dedicated our efforts to programming the second challenge, focusing on implementing and refining the navigation and obstacle interaction logic.

----------------------------------

Fecha: 16/09/2025

Registro:

Hoy dedicamos nuestros esfuerzos a programar el segundo reto, enfocándonos en implementar y refinar la lógica de navegación e interacción con obstáculos.

-----------------------------

Mira el Short (https://youtube.com/shorts/ztvVpYsAlvQ)

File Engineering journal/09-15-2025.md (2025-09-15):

Date: 09/15/2025

Entry:

Today we dedicated our efforts to advancing the code development for Challenge 2 while simultaneously completing and organizing our GitHub documentation. We made significant progress in refining the navigation algorithms, particularly focusing on the vehicle's interaction with dynamic obstacles and the parking sequence logic. Additionally, we updated our engineering journal with detailed technical entries and created a comprehensive connection scheme diagram to clarify our electrical system setup. All repository requirements were meticulously addressed, including structured commit histories, detailed descriptions, and optimized file organization for clarity and accessibility.

-------------------------------------------

Fecha: 15/09/2025

Registro:

Hoy dedicamos nuestros esfuerzos a avanzar en el desarrollo de código para el Reto 2, mientras completábamos y organizábamos nuestra documentación en GitHub. Logramos progresos significativos en el refinamiento de los algoritmos de navegación, enfocándonos especialmente en la interacción del vehículo con obstáculos dinámicos y la lógica de secuencia de estacionamiento. Adicionalmente, actualizamos nuestro diario de ingeniería con entradas técnicas detalladas y creamos un diagrama completo de esquema de conexiones para clarificar la configuración de nuestro sistema eléctrico. Todos los requisitos del repositorio fueron meticulosamente atendidos, incluyendo historiales de commits estructurados, descripciones detalladas y una organización de archivos optimizada para claridad y accesibilidad.

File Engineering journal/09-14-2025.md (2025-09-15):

Date: 09/14/2025

Entry:

Today we focused on the code and logic for Challenge 2, refining navigation algorithms and obstacle interaction sequences.

-----------------------------------

Fecha: 14/09/2025

Registro:

Hoy nos enfocamos en el código y lógica para el Reto 2, refinando algoritmos de navegación y secuencias de interacción con obstáculos.

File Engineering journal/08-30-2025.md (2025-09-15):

Date: 08/30/2025

Entry:

Today, significant progress was made in finalizing the code for both competition challenges. The team focused on optimizing the navigation algorithms and enhancing the integration of sensor data from the VL53L1X Time-of-Flight sensors and the RPLidar A1. Multiple test runs were conducted to ensure the system operates reliably under competition conditions, with adjustments made to improve obstacle detection accuracy and path planning efficiency. The codebase was refined for stability, and all components are now functioning as expected. Final checks and performance evaluations will continue to ensure readiness for the competition.

-------------------------------------------

Fecha: 30/08/2025

Registro:

Hoy se realizaron avances significativos en la finalización del código para ambos desafíos de competencia. El equipo se enfocó en optimizar los algoritmos de navegación y mejorar la integración de datos de los sensores VL53L1X (Time-of-Flight) y el RPLidar A1. Se llevaron a cabo múltiples pruebas para garantizar que el sistema opere de manera confiable bajo condiciones de competencia, realizando ajustes para mejorar la precisión en la detección de obstáculos y la eficiencia en la planificación de rutas. El código se refinó para mayor estabilidad, y todos los componentes ahora funcionan como se esperaba. Las verificaciones finales y evaluaciones de rendimiento continuarán para asegurar la preparación para la competencia.

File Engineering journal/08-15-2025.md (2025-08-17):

Date: 08/15/2025

Entry:

Today we dedicated the session to testing the adapted vision model with the new camera configuration. Initial results show promising detection accuracy, though some fine-tuning is still required to optimize performance under different lighting conditions.

-------------------------------------------------------------------

Fecha: 15/08/2025

Registro:

Hoy dedicamos la sesión a probar el modelo de visión adaptado con la nueva configuración de cámara. Los resultados iniciales muestran precisión de detección prometedora, aunque aún se requiere ajuste fino para optimizar el rendimiento en distintas condiciones de iluminación.

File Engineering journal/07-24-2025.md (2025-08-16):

Date: 07/24/2025

Entry:

Today, We spent the day searching for a solution to the Raspberry Pi problem without success. We decided to make a backup of all files, wipe the entire system, and reinstall the operating system.  

During the process, we noticed some files were incomplete or marked as corrupted, which complicated the recovery. Despite this, we managed to restore most of the necessary files to continue with the project.

-------------------------------------------------------------------------------------

Fecha: 24/07/2025

Registro:

Hoy dedicamos el día a buscar una solución al problema de la Raspberry Pi, sin éxito. Decidimos hacer una copia de seguridad de todos los archivos, borrar el sistema por completo y reinstalar el sistema operativo.

Durante el proceso, notamos que algunos archivos estaban incompletos o marcados como corruptos, lo cual complicó la recuperación. A pesar de esto, logramos restaurar la mayoría de los archivos necesarios para continuar con el proyecto.

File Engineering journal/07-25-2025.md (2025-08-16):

Date: 07/25/2025

Entry:

Today, Necessary libraries for sensors and components were installed and compiled. Additionally, we recreated missing programs from scratch, but with greater ease since we had learned how to do it during previous days.  

This process helped solidify the codebase and optimize development for future phases.

--------------------------------------------------------------------------------------------------

Fecha: 25/07/2025

Registro:

Hoy instalamos y compilamos las bibliotecas necesarias para los sensores y componentes. Además, recreamos desde cero los programas faltantes, aunque con mayor facilidad gracias a la experiencia adquirida en días anteriores.

Este proceso nos permitió consolidar la base de código y optimizar el desarrollo para las siguientes fases del proyecto.

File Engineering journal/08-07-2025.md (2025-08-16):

Date: 08/07/2025

Entry:

After testing various hardware solutions to address the VL53L1X's wide light cone issue, we evaluated baffles with different inclination angles (10°, 5°, and 3°). Through comparative testing, we determined the 3° tilt provided the optimal balance - effectively reducing floor interference while maintaining sufficient detection range and accuracy. This hardware modification successfully resolved the measurement limitations we encountered previously.

-----------------------------------------------------

Fecha: 07/08/2025

Registro:

Tras probar varias soluciones hardware para el problema del cono de luz ancho del VL53L1X, evaluamos deflectores con diferentes ángulos de inclinación (10°, 5° y 3°). Las pruebas comparativas mostraron que la inclinación de 3° ofrece el mejor equilibrio - reduciendo efectivamente las interferencias del piso sin comprometer el rango ni la precisión de detección. Esta modificación resolvió satisfactoriamente las limitaciones de medición previas.

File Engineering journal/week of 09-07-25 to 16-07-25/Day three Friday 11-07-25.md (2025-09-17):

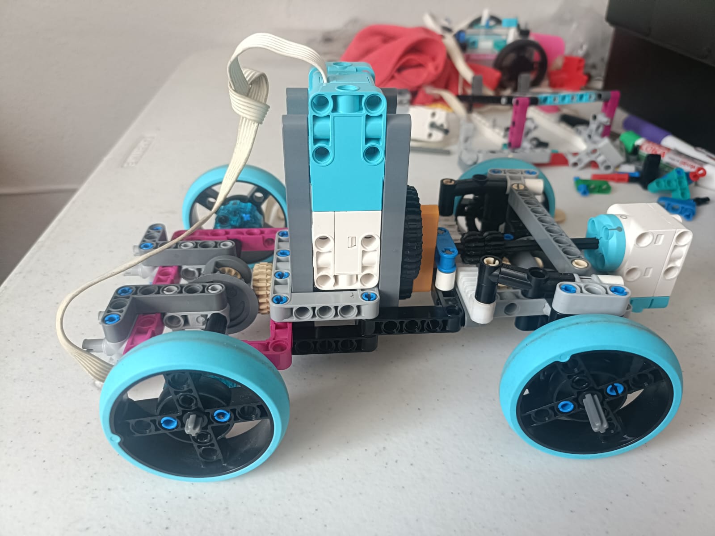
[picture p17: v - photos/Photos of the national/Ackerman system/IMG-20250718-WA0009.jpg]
v - photos/Photos of the national/Ackerman system/IMG-20250718-WA0009.jpg
The previously built Ackerman systems began to be implemented and tests were carried out to decide which one to use.   3D parts were also designed for the [rack and pinion system](https://github.com/alex309-duarte/WRO_FutureEngineers_Q/blob/main/3D%20pieces/pieza%20de%20cremallera%202.stl)

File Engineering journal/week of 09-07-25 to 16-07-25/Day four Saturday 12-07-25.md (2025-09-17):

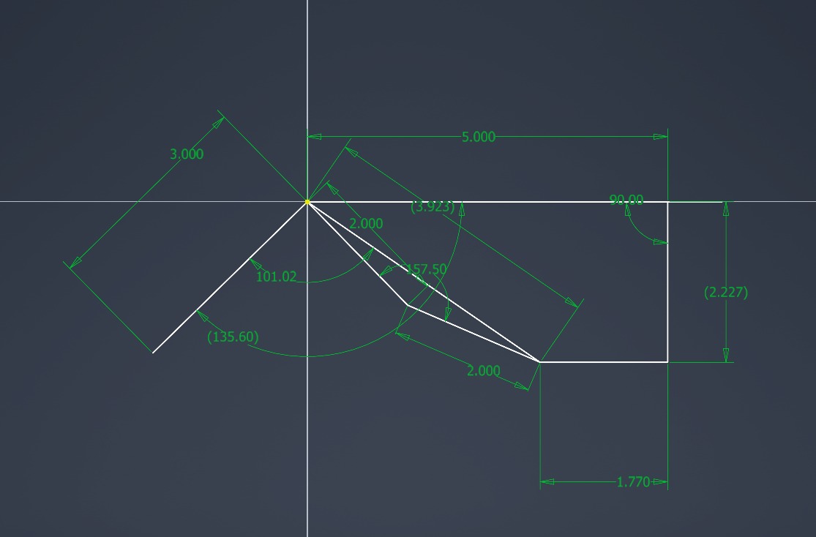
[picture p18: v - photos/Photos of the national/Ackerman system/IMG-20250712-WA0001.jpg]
v - photos/Photos of the national/Ackerman system/IMG-20250712-WA0001.jpg
The Ackerman systems, the two new ones that were built and that we had, were thoroughly analyzed. For this, trigonometry and AutoCAD were used.    Lego units were used to create diagrams and calculations. The idea of having a car with two Ackermans that turn in opposite directions to make tighter turns and make parking easier was also proposed.

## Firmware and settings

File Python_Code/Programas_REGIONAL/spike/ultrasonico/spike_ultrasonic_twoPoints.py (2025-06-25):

#!/usr/bin/env python3

import time
import lgpio
import threading
import queue
import signal
import sys
from dataclasses import dataclass
from typing import Optional, List, Dict, Tuple
"""
This module provides support for serial communication in Python.
"""
import serial
"""Added simplified script, originated from "interpreter_startup.py", starting here:"""
import subprocess
import os
import pty
# Configuration for each sensor
@dataclass
class UltrasonicSensor:
    name: str
    trigger_pin: int
    echo_pin: int
    last_reading: Optional[float] = None
    last_update: float = 0.0  # Timestamp of last successful reading

# Sensor configurations (trigger_pin, echo_pin)
SENSORS = [
    UltrasonicSensor("izquierda", trigger_pin=13, echo_pin=13),
    UltrasonicSensor("frente", trigger_pin=19, echo_pin=19),
    UltrasonicSensor("derecha", trigger_pin=6, echo_pin=6)
]

# Performance tuning parameters
MIN_MEASURE_INTERVAL = 0.04  # 30ms between measurements (about 33Hz per sensor)
SENSOR_TIMEOUT = 0.06      # 50ms timeout for echo pulse (reduced from 100ms)
SETTLE_TIME = 0.002         # 2ms settling time between trigger and echo
DISPLAY_UPDATE_RATE = 10    # Hz for display updates

# Speed of sound in cm/us
SPEED_OF_SOUND = 34300 / 1000000  # cm/s to cm/us

# Global flag for thread control
running = True

# Thread-safe queue for sensor updates
sensor_queue = queue.Queue()

def screenSimplified(): #Called main() in the original script, renamed to avoid conflict with the main function in this module.
    if not os.path.exists("/dev/ttyACM0"):
        return

    master_fd, slave_fd = pty.openpty() 
    
    subprocess.Popen( 
        ["screen", "/dev/ttyACM0", "115200"],
        stdin=slave_fd, 
        stdout=slave_fd,
        stderr=slave_fd,
    )

    os.close(slave_fd)
    time.sleep(1.0)
    os.write(master_fd, b'\x03') # Send Ctrl+C to screen
    time.sleep(0.2)
    os.write(master_fd, b'\x01') # Send Ctrl+A to screen
    time.sleep(0.2)
    os.write(master_fd, b'k') # Send 'k' to kill the screen session
    time.sleep(0.2)
    os.write(master_fd, b'y') # Send 'y' to confirm kill
    time.sleep(0.2)
    
    os.close(master_fd)

if __name__ == "__main__":
    screenSimplified()
    
"""End of simplified script, originated from "interpreter_startup.py" """

spike = serial.Serial('/dev/ttyACM0', 115200, timeout=1)
#variables globales rasp
der = -1
izq = 1

def initialize_Libraries():
    spike.write("import motor\r".encode()) 
    spike.readline()
    spike.write("from hub import port\r".encode())
    spike.readline()#clear buffer
    spike.write("from hub import motion_sensor\r".encode())
    spike.readline()#clear buffer
    spike.write("import distance_sensor\r".encode())
    spike.readline()#clear buffer
    #declare varianbles globales spike
    spike.write("der = -1\r".encode())
    spike.readline() #clear buffer
    spike.write("izq = 1\r".encode())
    spike.readline() #clear buffer
    spike.write("error = 0\r".encode())
    spike.readline() #clear buffer
    #declare functions for motors
    spike.write("def fr():\r".encode())
    spike.readline() #clear buffer 
    spike.write("motor.stop(port.F, stop = motor.HOLD)\r".encode())
    spike.readline() #clear buffer 
    spike.write("motor.stop(port.B, stop = motor.HOLD)\r".encode())
    spike.readline() #clear buffer
    end_Function()

    spike.write("def fc():\r".encode())
    spike.readline() #clear buffer 
    spike.write("motor.stop(port.F, stop = motor.COAST)\r".encode())
    spike.readline() #clear buffer 
    spike.write("motor.stop(port.B, stop = motor.COAST)\r".encode())
    spike.readline() #clear buffer
    end_Function()
    # centrar el vehiculo 
    spike.write("def cv():\r".encode())
    spike.readline() #clear buffer 
    spike.write("motor.run_to_absolute_position(port.F, 0, 550,\r".encode())
    spike.readline()#clear buffemotor.stop(port.F, stop = motor.COAST)r
    spike.write("direction = motor.SHORTEST_PATH, stop = motor.HOLD, acceleration = 1000, deceleration = 1000)\r".encode())
    spike.readline() #clear buffer
    spike.write("return 255\r".encode())
    spike.readline() #clear buffer
    end_Function()

    #pd 
    spike.write("def pd(s1,s2,vel,kp,kd,ea):\r".encode()) #ea es error anterior
    spike.readline() #clear buffer 
    spike.write("error=s1-s2\r".encode())
    spike.readline()#clear buffer
    spike.write("et= (kp*error) + (kd*(error-ea))\r".encode()) #et es error total
    spike.readline()#clear buffer
    spike.readline() #clear buffer
    spike.write("motor.run_to_absolute_position(port.F, int(et), 300, direction = motor.SHORTEST_PATH, stop = motor.HOLD, acceleration = 10000)\r".encode())
    spike.readline() #clear buffer
    spike.write("motor.set_duty_cycle(port.B, (-100)*(vel))\r".encode())
    spike.readline() #clear buffer
    spike.write("return error\r".encode())
    spike.readline() #clear buffer
    end_Function()

    #reset Gyro
    spike.write("def rg(grados):\r".encode())
    spike.readline() #clear buffer
    spike.write("motion_sensor.reset_yaw(grados)\r".encode())
    spike.readline() #clear buffer
    end_Function()

    #avanzar derecho
    spike.write("def ad(vel,referencia):\r".encode())
    spike.readline() #clear buffer
    spike.write("global error\r".encode())
    spike.readline() #clear buffer
    spike.write("error = pd(((10)*(referencia)),motion_sensor.tilt_angles()[0],vel,0.3,1,error)\r".encode())
    spike.readline() #clear buffer 
    end_Function()

    #avanzar derecho indefinido
    spike.write("def ai(vel,referencia):\r".encode())
    spike.readline() #clear buffer
    spike.write("error = 0\r".encode())
    spike.readline() #clear buffer
    spike.write("while 1:\r".encode())
    spike.readline() #clear buffer
    spike.write("error = pd(((10)*(referencia)),motion_sensor.tilt_angles()[0],vel,0.3,1,error)\r".encode())
    spike.readline() #clear buffer 
    spike.write(chr(127).encode()) #suprimir linea
    spike.readline() #clear buffer
    end_Function()

    spike.write("def vuelta(direccion,velocidad,grados):\r".encode())
    spike.readline() #clear buffer
    spike.write("motor.run_to_absolute_position(port.F, 49*(direccion), 550, direction = motor.SHORTEST_PATH)\r".encode())
    spike.readline() #clear buffer
    spike.write("while abs(grados*10) > abs(motion_sensor.tilt_angles()[0]):\r".encode())
    spike.readline() #clear buffer
    spike.write("motor.set_duty_cycle(port.B, (-100)*(velocidad))\r".encode())
    spike.readline() #clear buffer
    spike.write(chr(127).encode()) #suprimir linea
    spike.readline() #clear buffer
    spike.write("fr()\r".encode())   
    spike.readline() #clear buffer
    spike.write("return 255\r".encode())
    spike.readline() #clear buffer
    end_Function()
    end_Function()

    spike.write("def da(vel, referencia):\r".encode())
    spike.readline() #clear buffer
    spike.write("global error\r".encode())
    spike.readline() #clear buffer
    spike.write("error = pd(referencia,motion_sensor.tilt_angles()[0],vel,0.3,1,error)\r".encode())
    spike.readline() #clear buffer
    end_Function()

    spike.write("def ag(vel,grados,referencia):\r".encode())
    spike.readline() #clear buffer
    spike.write("error = 0\r".encode())
    spike.readline() #clear buffer
    spike.write("motor.reset_relative_position(port.B,0)\r".encode())
    spike.readline() #clear buffer
    spike.write("while abs(grados) > abs(motor.relative_position(port.B)):\r".encode())
    spike.readline() #clear buffer
    spike.write("error = pd(((10)*(referencia)),motion_sensor.tilt_angles()[0],vel,0.3,1,error)\r".encode())
    spike.readline() #clear buffer
    spike.write(chr(127).encode()) #suprimir linea
    spike.readline() #clear buffer
    spike.write("fc()\r".encode())
    spike.readline() #clear buffer
    spike.write("return 255\r".encode())
    spike.readline() #clear buffer
    end_Function()
    end_Function()

    spike.write("def spd(vel,distancia,sensor):\r".encode())
    spike.readline() #clear buffer
    spike.write("global error\r".encode())
    spike.readline() #clear buffer
    spike.write("error = pd(distancia,sensor,vel,0.3,1,error)\r".encode())
    spike.readline() #clear buffer
    spike.write("return motor.relative_position(port.B)\r".encode())
    spike.readline() #clear buffer
    end_Function()

    spike.write("def spi(vel,distancia,sensor):\r".encode())
    spike.readline() #clear buffer
    spike.write("global error\r".encode())
    spike.readline() #clear buffer
    spike.write("error = pd(sensor,distancia,vel,0.3,1,error)\r".encode())
    spike.readline() #clear buffer
    spike.write("return motor.relative_position(port.B)\r".encode())
    spike.readline() #clear buffer
    end_Function()


def centrar_vehiculo():
    spike.write("cv()\r".encode())
    spike.readline() #clear buffer    return_value = spike.readline().decode()
    return_value = spike.readline().decode()
    if return_value == "":
        return_value = "0"
    while int(return_value) != 255:
        return_value = spike.readline().decode()
        if return_value == "":
            return_value = "0"
    print("Fin de la vuelta")
    Free_spikeDirection()
    time.sleep(0.01)

def Free_spikeDirection():
    spike.write("fr()\r".encode())
    spike.readline() #clear buffer

def Coast_motors():
    spike.write("fc()\r".encode())
    spike.readline() #clear buffer


def end_Function():
    spike.write("\r".encode())
    spike.readline()#clear 
    spike.write("\r".encode())
    spike.readline()#clear buffer
    spike.write("\r".encode())
    spike.readline()#clear buffer
    
def reset_gyro(grados):
    spike.write(("rg("+str(grados)+")\r").encode())
    spike.readline() #clear buffer
    
def avanzar_distancia(vel,distancia,referencia):
    uls = [2000,2000,2000]
    i = 0
    while ((distancia*10) < uls[1]) or (uls[1] == -1):
        i = 0
        for sensor in SENSORS:
            if sensor.last_reading is not None:
                uls[i] = int(sensor.last_reading)
            i = i + 1
        spike.write(("ad("+str(vel)+","+str(referencia)+")\r").encode())
        spike.readline() #clear buffer
        print(uls[1])
    print("Fin del recorrido")

    Coast_motors()

def vuelta_grados(direccion,velocidad,grados):
    spike.write(("vuelta("+str(direccion)+","+str(velocidad)+","+str(grados)+")\r").encode())
    spike.readline() #clear buffer
    return_value = spike.readline().decode()
    if return_value == "":
        return_value = "0"
    while int(return_value) != 255:
        return_value = spike.readline().decode()
        if return_value == "":
            return_value = "0"
    print("Fin de la vuelta")
    Free_spikeDirection()
    time.sleep(0.01)

def avanzar_detection(vel,referencia):
    uls = [1,1,1]
    i = 0
    while uls[0] > 0 and uls[2] > 0 and uls[0] < 2000 and uls[2] < 2000:
        i = 0
        for sensor in SENSORS:
            if sensor.last_reading is not None:
                uls[i] = int(sensor.last_reading)
            i = i + 1
        spike.write(("da("+str(vel)+","+str(referencia)+")\r").encode())
        spike.readline() #clear buffer
    return uls
    #Coast_motors()

def avanzar_detection_gyro(vel,referencia):
    uls = [1,1,1]
    i = 0
    spike.write(("ai("+str(vel)+","+str(referencia)+")\r").encode()) #suprimir linea
    spike.readline() #clear buffer
    while uls[0] > 0 and uls[2] > 0 and uls[0] < 2000 and uls[2] < 2000:
        i = 0
        for sensor in SENSORS:
            if sensor.last_reading is not None:
                uls[i] = int(sensor.last_reading)
            i = i + 1
    spike.write(chr(3).encode())
    spike.readline() #clear buffer
    spike.readline() #clear buffer
    spike.readline() #clear buffer
    spike.readline() #clear buffer
    Coast_motors()

def vuelta_automatica(velocidad, grados, uls):
    while 1:
        if uls[0] == -1 or uls[2] == -1:
            break
        i = 0
        for sensor in SENSORS:
            if sensor.last_reading is not None:
                uls[i] = int(sensor.last_reading)
            i = i + 1    
    print("vuelta = ",uls,"\n")
    if uls[0] == -1:
        vuelta_grados(izq,velocidad,grados)
    elif uls[2] == -1:
        vuelta_grados(der,velocidad,grados)
    Free_spikeDirection()

def avanzar_recto_grados(velocidad,grados,referencia):
    spike.write(("ag("+str(velocidad)+","+str(grados)+","+str(referencia)+")\r").encode())
    spike.readline() #clear buffer
    return_value = spike.readline().decode()
    if return_value == "":
        return_value = "0"
    while int(return_value) != 255:
        return_value = spike.readline().decode()
        if return_value == "":
            return_value = "0"
    print("Fin de la vuelta")
    Coast_motors()

def seguir_pared_derecho(velocidad,grados):
    uls = [1,1,1]
    i = 0
    for sensor in SENSORS:
        if sensor.last_reading is not None:
            uls[i] = int(sensor.last_reading)
        i = i + 1
    ditancia_Inicial = uls[2]
    spike.write("motor.reset_relative_position(port.B)\r".encode())
    spike.readline() #clear buffer
    gradosMotor = 0
    while abs(gradosMotor) < grados:
        i = 0
        for sensor in SENSORS:
            if sensor.last_reading is not None:
                uls[i] = int(sensor.last_reading)
            i = i + 1
        spike.write(("spd("+str(velocidad)+","+str(ditancia_Inicial)+","+str(uls[2])+")\r").encode())
        spike.readline() #clear buffer
        gradosMotor = int(spike.readline().decode())
    Coast_motors()


def seguir_pared_izquierdo(velocidad,grados):
    uls = [1,1,1]
    i = 0
    for sensor in SENSORS:
        if sensor.last_reading is not None:
            uls[i] = int(sensor.last_reading)
        i = i + 1
    ditancia_Inicial = uls[0]
    spike.write("motor.reset_relative_position(port.B)\r".encode())
    spike.readline() #clear buffer
    gradosMotor = 0
    while abs(gradosMotor) < grados:
        i = 0
        for sensor in SENSORS:
            if sensor.last_reading is not None:
                uls[i] = int(sensor.last_reading)
            i = i + 1
        spike.write(("spi("+str(velocidad)+","+str(ditancia_Inicial)+","+str(uls[0])+")\r").encode())
        spike.readline() #clear buffer
        gradosMotor = int(spike.readline().decode())
    Coast_motors()

def get_distance(h: int, sensor: UltrasonicSensor) -> Optional[float]:
    """Measures distance using an ultrasonic sensor with minimal latency."""
    try:
        # Send trigger pulse (minimal delay)
        lgpio.gpio_claim_output(h, sensor.trigger_pin)
        lgpio.gpio_write(h, sensor.trigger_pin, 0)
        time.sleep(0.00001)  # 1us (minimum)
        lgpio.gpio_write(h, sensor.trigger_pin, 1)
        time.sleep(0.000010)  # 10us (required by HC-SR04)
        lgpio.gpio_write(h, sensor.trigger_pin, 0)
        
        # Switch to input mode for echo (no delay)
        lgpio.gpio_claim_input(h, sensor.echo_pin)

        # Wait for the pulse to start (with timeout)
        timeout = time.time() + SENSOR_TIMEOUT
        while lgpio.gpio_read(h, sensor.echo_pin) == 0:
            if time.time() > timeout:
                return None

        pulse_start = time.time()
        
        # Wait for the pulse to end (with timeout)
        timeout = time.time() + SENSOR_TIMEOUT
        while lgpio.gpio_read(h, sensor.echo_pin) == 1:
            if time.time() > timeout:
                return None
        
        pulse_end = time.time()
        
        # Calculate distance in cm
        pulse_duration = pulse_end - pulse_start
        distance = (pulse_duration * SPEED_OF_SOUND * 10000000) / 2

        # Filter out invalid readings
        if 20 <= distance <= 2000:  # 4m max reliable range
            return distance
        else:
            return -1

    except Exception as e:
        print(f"Error reading {sensor.name} sensor: {e}")
        return None

def sensor_worker(h: int, sensor: UltrasonicSensor):
    """Worker function to continuously read a sensor with minimal latency"""
    last_measure_time = 0
    
    while running:
        current_time = time.time()
        
        # Only measure if enough time has passed since last measurement
        if current_time - last_measure_time >= MIN_MEASURE_INTERVAL:
            distance = get_distance(h, sensor)
            if distance is not None:
                sensor.last_reading = distance
                sensor.last_update = current_time
                sensor_queue.put((sensor.name, distance))
            last_measure_time = current_time
        else:
            # Small sleep to prevent 100% CPU usage
            time.sleep(0.001)  # 1ms

def setup_gpio():
    """Initialize GPIO and claim all necessary pins"""
    try:
        h = lgpio.gpiochip_open(0)
        
        # Setup all sensor pins
        for sensor in SENSORS:
            lgpio.gpio_claim_output(h, sensor.trigger_pin)
            lgpio.gpio_claim_input(h, sensor.echo_pin)
            lgpio.gpio_write(h, sensor.trigger_pin, 0)  # Ensure trigger is low
        
        # Let sensors settle
        print("Initializing sensors...")
        time.sleep(1)
        return h, True
        
    except Exception as e:
        print(f"GPIO initialization failed: {e}")
        return None, False

def cleanup_gpio(h):
    """Release all GPIO resources"""
    try:
        for sensor in SENSORS:
            try:
                lgpio.gpio_free(h, sensor.trigger_pin)
                lgpio.gpio_free(h, sensor.echo_pin)
            except:
                pass
        lgpio.gpiochip_close(h)
        print("GPIO resources cleaned up")
    except:
        pass
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

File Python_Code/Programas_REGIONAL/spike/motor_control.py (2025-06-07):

from pybricks.hubs import PrimeHub
from pybricks.pupdevices import Motor
from pybricks.parameters import Port
from pybricks.tools import wait
import sys

# Motor B: Traccion (grande)
# Motor D: Direccion (mediano)

def limpiar_recursos_ackermann(motor_traccion_obj=None, motor_direccion_obj=None):
    print("\nLimpiando recursos Ackermann...")
    try:
        if motor_traccion_obj:
            motor_traccion_obj.brake()
        if motor_direccion_obj:
            motor_direccion_obj.brake()
        print("Motores Ackermann detenidos y recursos liberados.")
    except Exception as e:
        print(f"Error al limpiar recursos Ackermann: {e}")

print("Iniciando rutina Ackermann: Avanzar...")
motor_traccion = None
motor_direccion = None

try:
    hub = PrimeHub()
    print("Hub inicializado.")

    print("Inicializando motor de traccion (Puerto B)...")
    motor_traccion = Motor(Port.B)
    print("Motor de traccion inicializado.")

    print("Inicializando motor de direccion (Puerto D)...")
    motor_direccion = Motor(Port.D)
    print("Motor de direccion inicializado.")

    print("Iniciando secuencia de movimiento Ackermann.")

    print("Asegurando motor de direccion (D)...")
    motor_direccion.brake()
    wait(500)

    velocidad_traccion = 50
    tiempo_avance_ms = 5000
    print(f"Moviendo motor de traccion (B) adelante al {velocidad_traccion}% durante {tiempo_avance_ms / 1000}s...")
    motor_traccion.dc(velocidad_traccion)
    wait(tiempo_avance_ms)

    print("Deteniendo motor de traccion (B)...")
    motor_traccion.brake()
    wait(500)

    print("Rutina de avance Ackermann completada.")

except Exception as e:
    print(f"\nError durante la rutina Ackermann: {e}")
finally:
    print("Ejecutando limpieza final Ackermann...")
    limpiar_recursos_ackermann(motor_traccion, motor_direccion)
    print("Script Python Ackermann finalizado.")

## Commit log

2025-06-07 initial_commit
    communication between raspberry Pi 5 and spike prime
2025-06-25 open challenge
    first part of the future engineer challenge
    ultrasonic sensor usage along side with spike prime motor
2025-07-17 Add files via upload
    3D model of the robot for the national WRO Mexico made with Studio 2.0 and using Lego pieces as a base, it still needs to import batteries, Raspberry, Lidar, sensors
2025-07-18 Several 3D parts were made for the new robot that was built.
    These are the 3D modeled pieces that were made for the Ackerman systems that we were going to use and a piece designed specifically to place the Raspberry.
2025-07-18 Add files via upload
    This will be the support that will be used for the new on/off button.
2025-07-18 More photos of the Ackerman system prototypes
2025-09-17 photos of lidar
